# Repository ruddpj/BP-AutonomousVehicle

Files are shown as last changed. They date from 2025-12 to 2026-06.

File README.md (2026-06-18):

# Autonómne riadenie malého vozidla s detekciou prekážky
Autor: Rudolf Tisoň

plot

## 📌 Popis projektu
Tento projekt sa zameriava na autonómne riadenie malého vozidla pomocou počítačového videnia. Vozidlo dokáže sledovať jazdný pruh (čiaru) a zároveň detegovať prekážky v reálnom čase.

Na spracovanie obrazu sa využíva knižnica OpenCV a model YOLO, pričom riadenie vozidla zabezpečuje mikrokontrolér Arduino Nano ESP32 v kombinácii s kamerovým modulom ESP32-CAM.

## ⚙️ Použité technológie
🐍 Python

👁️ OpenCV

🤖 YOLO (You Only Look Once)

🔌 Arduino Nano ESP32

📷 ESP32-CAM

## 🚀 Funkcionalita
Detekcia jazdného pruhu (line following)

Detekcia prekážok pomocou YOLO

Rozhodovanie:

pokračovanie v jazde

zastavenie pri prekážke

Spracovanie obrazu v reálnom čase

Komunikácia medzi PC a mikrokontrolérom

## 🧠 Princíp fungovania
ESP32-CAM streamuje obraz do počítača

Python skript spracováva obraz:

OpenCV → detekcia jazdného pruhu

YOLO → detekcia prekážok

Na základe detekcie sa vypočíta:

- smer (steering)

- stav (jazda / stop)

Príkazy sa odošlú do Arduino Nano ESP32

Vozidlo reaguje na riadiace signály

## 🛠️ Inštalácia
1. Klonovanie repozitára
```bash
git clone https://github.com/ruddpj/BP-AutonomousVehicle.git
cd BP-AutonomousVehicle
```
2. Inštalácia závislostí
```bash
pip install opencv-python ultralytics numpy
```

## ▶️ Spustenie
```bash
python Python/main.py
```

## 🔌 Hardvér
- Arduino Nano ESP32

- ESP32-CAM + OV2640

- DRV8833

- HC-SR04

- 2x 3V 300RPM DC motory

- Buck menič nepätia

- Napájanie (batéria)

## 📂 Štruktúra projektu
```
.
├── Arduino/
├── Model/
├── Presentation/
├── Python/
├── Testing/
├── Thesis/
├── .gitignore
├── LICENSE
├── README.md
└── yolov8s.pt
```

## 🎓 Účel projektu
Projekt bol vytvorený ako súčasť štúdia (bakalárska práca) a slúži na demonštráciu využitia počítačového videnia v autonómnych systémoch.

## 📜 Licencia
Tento projekt je licencovaný pod GNU GPL-3.0

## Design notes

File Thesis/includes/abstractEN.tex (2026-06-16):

The objective of this bachelor's thesis was to design and implement a small vehicle capable of autonomous driving and obstacle detection using computer vision methods. The vehicle was equipped with an ESP32-CAM camera module and an ultrasonic sensor, which continuously monitored the area ahead and provided data for a control server operating in the Python programming language. An important element of the solution was image processing in the OpenCV library, where maintaining the vehicle within the center line of the lane was ensured through color thresholding and contour detection in a defined region of interest. For obstacle detection, a YOLOv8 convolutional neural network was integrated into the system, which, together with distance measurement, enabled the vehicle to respond smoothly to objects. The entire hardware system was controlled by the Arduino platform, while image processing took place on the server, which communicated wirelessly with the vehicle via Wi-Fi.

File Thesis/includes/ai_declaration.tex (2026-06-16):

\begin{trivlist}
\item Google (2026), Gemini 3 Fast, celý text, úprava štylizácie a reformulácia textu.

\item Google (2026), Gemini 3.1 Flash, abstrakt, preklad textu do angličtiny. 

\item OpenAI (2026), GPT-5.4, zdrojový kód, generovanie základnej štruktúry kódu pre Arduino, ESP32-CAM a server v jazykoch C++ a Python.
\end{trivlist}

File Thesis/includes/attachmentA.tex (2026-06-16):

\pagenumbering{Roman}
V prílohe sa nachádza archív \verb|zdrojovy_kod.zip| so zdrojovými kódmi pre vozidlo a server.
Zdrojový kód projektu je dostupný aj na:\par
\url{https://github.com/ruddpj/BP-AutonomousVehicle.git}.
\vspace*{50px}
\newline
\textbf{Arduino programy}
\begin{itemize}
	\item Arduino/
		\begin{itemize}
			\item ArduinoController/ArduinoController.ino
			\item WifiCamera/WifiCamera.ino
		\end{itemize}
\end{itemize}
\textbf{Python programy}
\begin{itemize}
	\item Python/
		\begin{itemize}
			\item connect.py
			\item detect.py
			\item interpret.py
			\item main.py
			\item remote.py
			\item transform.py
		\end{itemize}
\end{itemize}

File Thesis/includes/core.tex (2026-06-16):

\section{Autonómne vozidlá}\label{sec:AutonomneVozidla}
\subsection{Čo je to autonómne vozidlo?}\par
\acrfull{av}, niekedy nazývané aj samoriadiace auto je dopravný prostriedok, ktorý, na rozdiel od tradičných vozidiel nevyžaduje vodiča. Autonómne vozidlá vykonávajú túto úlohu pomocou viacerých hardvérových a softvérových systémov. Hoci ani v roku 2026 nemá termín 'samoriadiace' jednotnú štadardnú definíciu, hlavným cieľom týchto technológií zostáva eliminácia ľudských chýb, zvýšenie efektivity premávky a sprístupnenie prepravy ľudom, ktorí nie sú schopní šoférovať sami~\cite{wevolver2020}.\par
Na vnímanie okolia vozidla používame senzory detekcie objektov. Systém vnímania používa kamery, \acrfull{radar}, \acrfull{lidar} a ultrazvukové senzory, pričom každý z nich má špecifickú funkciu. Autonómne vozidlá často pracujú s čiastočne neznámym a dynamickým prostredím, preto si musia vystavať model svojho prostredia a zároveň sa v ňom lokalizovať. Tento proces je známy pod skratkou SLAM (súčasná lokalizácia a mapovanie)~\cite{wevolver2020}.\par
Spočíva v spracovaní dát zo senzorov, máp a systéme \glslink{gps}{globálneho polohovacieho systému} (\acrshort{gps}), vďaka čomu si zariadenie vytvorí model prostredia a určí v ňom svoju polohu v reálnom čase~\cite{wevolver2020}.\par
Tretí systém je zodpovedný za plánovanie a rozhodovanie. Na základe dát z predchádzajúcej vrstvy vozidlo vyhodnocuje a reaguje na vývoj dopravnej situácii. Táto vrstva má mnoho funkcií od plánovania trasy po vyhýbanie sa prekážkam. Najčastejšie sa používajú modely strojového učenia, vrátane neurónových sietí~\cite{wevolver2020}.\par
Posledným článkom je konanie a ovládanie. Systém ovládania vozidla premení abstraktné požiadavky predchádzajúcej vrstvy na fyzické pohyby auta. Zodpovedá za smerové riadenie, zrýchľovanie a brzdenie.\par
Pokročilé algoritmy zároveň zabezpečujú, aby pohyb bol plynulý, stabilný a rešpektoval limitácie podvozku. Vďaka integrácii týchto systémov dokáže autonómne vozidlo navigovať v komplexných dopravných situáciách s minimálnou až nulovou potrebou ľudského zásahu~\cite{wevolver2020}.
\subsection{Úrovne autonómnych vozidiel}
Úrovne autonómnych vozidiel sú definované organizáciou SAE International v štandarde SAEJ3016. Tento dokument delí automatizáciu riadenia do šiestich stupňov (0--5) podľa toho, akú časť jazdy zabezpečuje systém a akú úlohu ešte stále zohráva vodič. O samoriadiacich autách sa často hovorí, ako o jednej kategórii, no v praxi ide o postupný vývoj od minimálnej podpory riadenia až po úplnú autonómiu vozidla bez zásahu človeka~\cite{saej3016}.
\subsubsection{Úroveň 0}
\paragraph{Žiadna automatizácia}Na tejto úrovni všetky činnosti vykonáva ľudský vodič. Vozidlo môže mať bezpečnostné systémy, ako napríklad upozornenie opustenia jazdného pruhu, no samotné riadenie je plne v rukách človeka~\cite{saej3016}.
\subsubsection{Úroveň 1}
\paragraph{Asistované riadenie}Systém pomáha s postranným alebo pozdĺžnym riadením vozidla ale nie v obidvoch prípadoch naraz. Sem patria asistencie, ako udržiavanie rýchlosti (tempomat) alebo mierne korigovanie smeru. Vodič však musí neustále sledovať situáciu na vozovke a mať ruky na volante~\cite{saej3016}.
\subsubsection{Úroveň 2}
\paragraph{Čiastočná automatizácia}Vozidlo dokáže súčasne riadiť smer aj rýchlosť, stále však platí, že vodič nepretržite dohliada na jazdu a je pripravený zasiahnuť v prípade núdze. Systém vykonáva viac úloh riadenia naraz, no zodpovednosť upadá na človeka~\cite{saej3016}.
\subsubsection{Úroveň 3}
\paragraph{Podmienená automatizácia}Jazda v špecifickej situácii je automatizovaná a vodič nemusí aktívne sledovať okolie. Ak však systém vyhodnotí, že situáciu nezvládne, kontrola vozidla sa vráti vodičovi. Vodič musí byť pripravený prevziať kontrolu nad vozidlom~\cite{saej3016}.
\subsubsection{Úroveň 4}
\paragraph{Vysoká automatizácia}Na tejto úrovni je vozidlo schopné zvládnuť jazdu úplne samo v rámci definovaných prostredí alebo podmienok. V prípade, že sa vozidlo dostane mimo týchto podmienok, dokáže bezpečne zastaviť. Prítomnosť ľudského šoféra nie je nutná~\cite{saej3016}.
\subsubsection{Úroveň 5}
\paragraph{Plná automatizácia}Najvyšší stupeň automatizácie, vozidlo dokáže jazdiť samostatne za všetkých podmienok, v ktorých dokáže jazdiť človek. Neexistuje potreba vodiča. Vozidlo zastaví v prípade zlyhania určitých modulov riadenia~\cite{saej3016}.

\section{Ciele práce}\label{sec:CielePrace}
V tejto kapitole si stanovíme hlavný cieľ bakalárskej práce a taktiež čiastkové ciele, ktoré slúžia, ako miľníky pri praktickom spracovaní témy práce.\par
Hlavný cieľ bakalárskej práce je návrh a implementácia algoritmu pre autonómne riadenie malého robotického vozidla, ktoré dokáže v reálnom čase detegovať prekážky v jazdnej dráhe a následne na ne reagovať.\par
Praktická časť práce sa zameriava na implementáciu riešenia na hardvérovej platforme Arduino so súčasnými metódami počítačového videnia pomocou knižnice OpenCV.\par
\subsection{Čiastkové ciele}
\begin{enumerate}
	\item \textbf{Analýza problematiky:} Teoretické spracovanie aktuálnej problematiky v oblasti autonómnych vozidiel. Zhodnotenie súčasnej a budúcej implementácie jednotlivých systémov použitých v \acrshort{av}. Prehľad konkrétneho využitia senzorových systémov a umelej inteligencie na detekciu prekážok.

	\item \textbf{Návrh technologického riešenia:} Výber optimálnej kombinácie hardvérových a softvérových komponentov v rámci obmedzenia bakalárskej práce. Zvolenie riadiacej jednotky Arduino, typ a počet senzorov, programovací jazyk riešenia a mechanické prvky vozidla. Výber metód detekcie prekážky a jazdného pruhu pomocou počítačového videnia. Fyzický návrh vzhľadu vozidla so zameraním na použité materiály a rozloženie komponentov.

	\item \textbf{Algoritmizácia detekcie:} Zvolenie riešení v prostredí OpenCV zameraných na spracovanie obrazu z kamery na identifikáciu prekážok a jazdného pruhu v zornom poli vozidla.

	\item \textbf{Prepojenie komponentov:} Návrh metód komunikácie jednotlivých komponentov. Prepojenie vrstiev riadenia autonómneho vozidla od vnímania po konanie. Interpretácia výstupov na vstupy pre jednotlivé systémy. Návrh fyzického prepojenie častí systému pomocou komunikačného média.

	\item \textbf{Zostavenie riešenia:} Implementácia zvolených návrhov. Naprogramovanie riešenia s použitím knižnice OpenCV. Zostavenie rámu vozidla a následná montáž.

	\item \textbf{Testovanie a validácia:} Navrhnutie metodiky testovania a následné overenie funkčnosti vozidla v rozličných situáciách. Otestovanie detekcie rôznych prekážok.
\end{enumerate}

\section{Analýza súčasného stavu}\label{sec:Analyza}
\subsection{Aktuálny stav technológie}
V posledných rokoch sme zaznamenali nárast vozidiel s treťou úrovňou autonómie, autonómne taxi služby sa v mestách stávajú reálnym spôsobom dopravy a videli sme už aj prvé ukážky kamiónov bez nutnosti ľudského vodiča~\cite{electronics2022}\cite{mckinsey2026}.\par
Vďaka vývoju v oblasti umelej inteligencie a zvýšenia výkonu výpočtových platforiem sme zaregistrovali značný pokrok v technológiách autonómnych vozidiel. Výrobcovia sa snažia zlepšovať kombinácie \glslink{radar}{radarových}, \acrshort{lidar}ových a kamerových dát tak, aby boli robustnejšie voči dopravným a poveternostným podmienkam. Pokračuje snaha v návrhu scenárov pre hraničné situácie, čím sa zlepší percepčná schopnosť autonómnych systémov a zrýchli ich nasadenie~\cite{motortrend2026}\cite{nvidia2026}.\par
Autonómne vozidla zaznamenali značnú investíciu ale aj kontrolu zo strany štátnych a nadnárodných organizácií. Spoločnosti, ktoré poskytujú služby samoriadiacich vozidiel rozširujú svoju dostupnosť, znižujú počet senzorov a náklady na hardvér. Hoci technologický pokrok napreduje, integrácia do infraštruktúry mesta zostáva podstatnou výzvou pre adopciu \acrshort{av} do dopravy. Štandard SAE International preto opisuje plán prechodu od asistencie šoférovania po plne autonómnu prevádzku~\cite{theguardian2026}\cite{waymo2026}.
\subsubsection{Umelá inteligencia}
\acrfull{ai} vykonáva dôležitú funkciu v percepčnom, rozhodovacom a plánovacom systéme autonómneho vozidla, čím nahrádza rolu ľudského vodiča. Moderné systémy používajú strojové učenie (machine learning) na detekciu hazardov na ceste, klasifikáciu dopravných značiek a sledovanie a predikciu pohybu chodcov a ostatných vozidiel~\cite{hamza2023}.\par
V súčasnosti sa autonómne modely trénujú na obrovskom množstve anotovaných obrázkov, videí, simulácií a skutočných jazdných dát, aby v praxi zvládli širokú škálu scenárov. Hlboké učenie (deep learning) a učenie posilňovaním (reinforcement learning) sa používajú v novodobých autonómnych vozidlách. Deep learning, podskupina strojového učenia, pracuje na princípe viacvrstvových neurónových sietí, čím sa fungovaním podobá ľudskému mozgu. Reinforcement learning mení správanie modelu využitím systému odmien a penalizácií~\cite{grigorescu2019}.\par
Napriek značnej komplexnosti zostáva riešenie hraničných prípadov (edge cases) zásadnou výzvou pre dnešné systémy. Potreba veľkého množstva tréningových dát a vysoká hranica bezpečnosti a spoľahlivosti výrazne spomaľuje nasadenie vozidiel do reálnej premávky~\cite{nvidia2026}.
\subsubsection{Senzory}
Senzory sú spôsob akým autonómne vozidlá vnímajú svoje okolie. Ako je možné vidieť na obrázku \ref{fig:sensors}, v súčasnosti sa v autách využíva kombinácia kamier, \acrshort{lidar}ových, \glslink{radar}{radarových} a ultrazvukových senzorov~\cite{badue2021}.\par
\begin{figure}[!ht]
	\centering
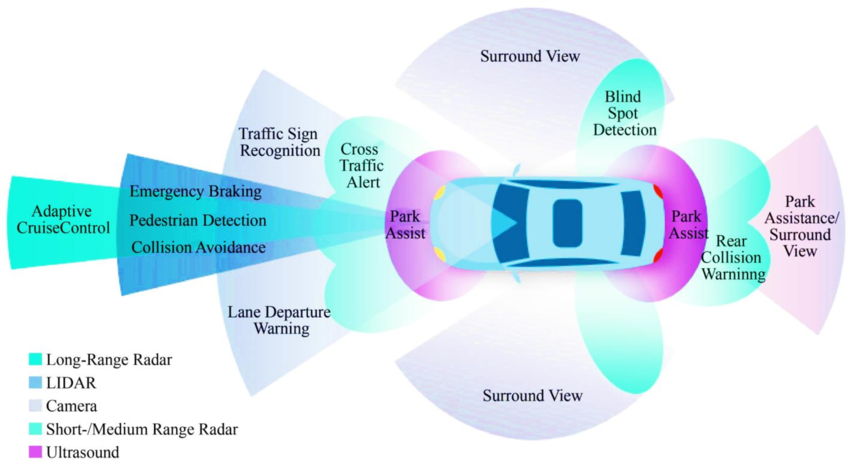
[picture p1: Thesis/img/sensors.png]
	
	\caption{Ako \acrshort{av} vnímaju prostredie}
	\parbox{9cm}{\centering\footnotesize{\cite{hamza2023}, licencia: \href{https://creativecommons.org/licenses/by-sa/4.0/deed.en}{CC BY-SA 4.0}.}}
	\label{fig:sensors}
\end{figure}
Kamery predstavujú najrozšírenejší typ senzorov; sú nákladovo efektívne, no citlivé na zlé osvetlenie a počasie. Používajú sa na detekciu jazdných pruhov, rozpoznávanie dopravných značiek a identifikáciu chodcov a vozidiel. \acrshort{radar} využíva elektromagnetické vlny na meranie vzdialenosti a rýchlosti. Používa sa najmä pre detekciu vzdialených objektov aj v nepriaznivých poveternostných podmienkach (dážď, hmla, sneh). \acrshort{lidar} používa laserové impulzy na vytvorenie detailného trojrozmerného modelu okolia, no okrem vysokých nákladov je aj viac náchylný na zlé počasie. Ultrazvukové senzory majú využitie v detekcii objektov na krátke vzdialenosti, napríklad pri parkovacích manévroch. Na rozdiel od fotoelektrických senzorov (napr. \acrshort{radar}), nie sú ovplyvnené farbou alebo odrazivosťou cieľa, pretože používajú zvuk a nie svetlo~\cite{wevolver2020}\cite{badue2021}.\par
Súčasný vývoj v oblasti senzorov sa zameriava primárne na zvyšovanie presnosti meranie, optimalizovanie počtu potrebných senzorov a výrazné znižovanie ich ceny. Výrobcovia taktiež zefektívňujú kombinovanie dát viacerých senzorov, tzv. senzorovú fúziu, čím zvyšujú presnosť a spoľahlivosť systému~\cite{waymo2026}\cite{hamza2023}.
\subsection{Použitie autonómnych vozidiel}
Autonómne vozidlá ponúkajú široké spektrum využitia, pričom ich možnosti sa v posledných rokoch rozširujú. K najpozoruhodnejším oblastiam ich využitia patrí doprava. Hlavným cieľom je zvýšiť bezpečnosť a plynulosť premávky. Ďalšie využitie je v logistike tovaru, kde nahrádzajú rutinnú manuálnu prácu tradične vykonávanú ľudmi.\par
\subsubsection{Autonómne taxi služby}
Autonómne taxi služby, často nazývané robotaxíky, predstavujú jednu z najpokročilejších foriem využitia autonómnych technológií. Celý proces -- od objednania a naplánovania trasy až po samotnú prepravu pasažierov -- je plne automatizovaný.\par
Mnohí výrobcovia automobilov, technologické spoločnosti a štátne organizácie investujú zdroje do vývoja robotaxíkov. Na popredí stojí spoločnosť Waymo, dcérska spoločnosť amerického konglomerátu Alphabet. Ich vozidlá, spĺňajúce štvrtú úroveň autonómie, využívajú \acrshort{lidar}, \acrshort{radar} a kamery na vytváranie trojrozmerného obrazu okolia. S každou ďalšou generáciou vozidiel navyše redukujú počet senzorov, čím znižujú výrobné náklady a zlepšujú škálovateľnosť celého projektu~\cite{waymo2026}.\par
Alternatívny prístup zvolila spoločnosť Tesla so svojou službou Robotaxi a systémom FSD (Full Self-Driving), ktorý predstavuje tretí stupeň autonómneho riadenia. Na rozdiel od konkurencie nepoužíva finančne nákladné \acrshort{lidar} senzory, ale spolieha sa výhradne na kamerový systém s interpretáciou dát pomocou umelej inteligencie. Hoci pri bežných vozidlách nad jazdou stále dohliada ľudský operátor pripravený kedykoľvek prevziať kontrolu, v roku 2026 začala spoločnosť do svojej flotily zavádzať prvé vozidlá v plne autonómnom režime bez ľudského dozoru~\cite{notateslaapp2026}.\par
Ďalším významným hráčom je spoločnosť Nvidia s modelom Alpamayo 1. Tento open-source model uvažovania je navrhnutý a trénovaný špeciálne na zvládanie komplexných a kritických dopravných situácií. Vydanie tohto voľne dostupného riešenia má za cieľ výrazne urýchliť integráciu štvrtej a piatej úrovne \acrshort{av} do bežnej premávky~\cite{nvidia2026}.
\subsubsection{Autonomizácia donášky jedla}
\glslink{adr}{Autonómne doručovacie roboty}~(\acrshort{adr}) sa používajú v súčasnosti v univerzitných kampusoch a mestách na donášku jedla. Poskytujú takzvanú last-mile delivery (dodanie na poslednú míľu) a fungujú na štvrtej úrovni autonómie. Primárne využívané na chodníkoch alebo cyklochodníkoch, doručovacie roboty sú schopné prekonávať križovatky, vyhýbať sa prekážkam a doručovať tovar na vzdialenosť pár kilometrov~\cite{srinivas2022}.\par
\acrshort{adr} používajú zväčša kombináciu kamier a počítačového videnia na navigovanie, týmto spôsobom zabezpečujú nižšie náklady na výrobu, s väčšou mierou škálovateľnosti. Niektorí výrobcovia sa vyhýbajú používaniu \acrshort{gps}, pretože neposkytuje dostatočnú mieru presnosti~\cite{forbes2025}.\par
Autonómna donáška jedla zaznamenala výrazný rozvoj počas pandémie COVID-19. Mnohé spoločnosti poskytujúce donášku jedla, ako napríklad Uber Eats a DoorDash, ale aj logistické spoločnosti, ako Amazon, Walmart a Google začali investovať do vývoja \acrshort{adr}. Jedným z priekopníkov v tejto oblasti je spoločnosť Starship Technologies, ktorá výrazne rozšírila svoju flotilu práve počas pandémie. Zatiaľ čo donáška pomocou pozemných robotov je bežná, mnohé spoločnosti investujú aj do vývoja doručovania pomocou autonómnych dronov~\cite{forbes2025}.\par
Značným problémom \acrshort{adr} je ich krátky dosah, pomalá rýchlosť a obmedzená kapacita užitočného zaťaženia. Mnohé spoločnosti investujú do hybridných modelov donášky kombináciou konvenčných donáškových vozidiel a doručovacích robotov~\cite{srinivas2022}.\par
V závislosti od charakteristík systému možno existujúci model hybridného doručovania klasifikovať, ako nasledujúce tri kategórie:
\begin{itemize}
	\item \textbf{Dvojúrovňový model:} Tento model využíva konvenčné vozidlá (kamióny alebo dodávky) na hromadnú prepravu zásielok z centrálneho depa do siete menších lokálnych skladísk. Z týchto miest vykonávajú \acrshort{adr} donášku na poslednú míľu priamo zákazníkovi~\cite{srinivas2022}.
	\item \textbf{Mothership model:} V tomto modeli slúži štandardné doručovacie vozidlo ako materská loď, ktorá je špeciálne upravená na prepravu flotily \acrshort{adr}. Autonómne roboty sa z materskej lode vypúšťajú v bezprostrednej blízkosti koncových adries doručenia. Ide o jeden z najčastejšie skúmaných modelov v aktuálnej literatúre~\cite{srinivas2022}.
	\item \textbf{Model čaty} Autonómne vozidlá doručujú zásielky samostatne v oblastiach, ktoré sú schopné navigovať. Ak však musia prekonať zóny, ktoré sú pre roboty nedostupné, pripoja sa k manuálne riadenému vozidlu, ktoré funguje ako ,,vodca čaty''. Roboty nasledujú toto vozidlo, až kým nedorazia do zóny im vhodnej~\cite{srinivas2022}.
\end{itemize}
\subsection{Zhrnutie poznatkov}
Po analýze technologického vývoja autonómnych vozidiel je nevyhnutné kriticky zhodnotiť ich dopad na reálne dopravné prostredie. V nasledujúcej podkapitole si identifikujeme aktuálne trendy a vyvodíme poznatky, ktoré formujú súčasnú sféru autonómnej mobility.\par
Mnohé implementácie v priemysle autonómnych vozidiel sa posúvajú od asistovaných systémov úrovne 2 a 3, k plne autonómnej prevádzke v špecifických podmienkach úrovne 4. Plná autonómia úrovne 5 stále ostáva dlhodobým problémom v danej oblasti.\par
Počet senzorov sa v autonómnych vozidlách zdatne zmenšuje. Prechádza sa z ideológie ,,maximálnej redundancie'' s vysokým počtom senzorov na optimalizovaný prístup. Spoločnosti, ako Tesla nahrádzajú spoľahlivé, no ekonomicky nevýhodné \acrshort{lidar}ové senzory za kombináciu kamier a \acrshort{ai}.\par
Kontrastne, spoločnosti ako Waymo sa držia prístupu založeného na \acrshort{lidar}e, no snažia sa znížiť cenu a zvýšiť ich efektivitu. V súčasnosti ešte neexituje konsenzus medzi technologickými spoločnosťami.\par
\acrshort{ai} zohráva dôležitú rolu pri plánovacom a rozhodovacom systéme autonómnych vozidiel. Súčasné trendy ukazujú na využívanie jazykových modelov, ktoré sú schopné interpretovať dáta zo senzorov a z nich priamo rozhodnúť o chode autonómneho vozidla.\par
Hraničné situácie zohrávajú najväčšiu bariéru ku masovému nasadeniu autonómnych vozidiel úrovne 5. Vývoj v oblasti umelej inteligencii sa zameriava práve na tieto edge cases. Z analýzy vyplýva, že vyriešením tohto problému, bude zavedenie \acrshort{av} v mestách zdatne urýchlené.\par
Technológia samotná nestačí pre adopciu autonómnych vozidiel do miest. Značným problémom je integrácia v mestskom prostredí a verejná akceptácia \acrshort{av}. Predpokladáme, že krajiny, ktoré budú investovať do integrácie autonómnych vozidiel, a ktoré majú progresívny názor na ich nasadenie, budú zaznamenávať najväčší nárast v tomto sektore.\par
Viaceré z identifikovaných aspektov boli priamo reflektované v našom návrhu systému autonómneho vozidla s detekciou prekážok.

\section{Komponenty systému}\label{sec:Komponenty}
V tejto kapitole si preberieme použité komponenty celkového systému. Výber správnych súčastí v rámci limitácií bakalárskej práce je dôležitý pre získanie lepších výsledkov.
\subsection{Arduino Nano ESP32 mikrokontrolér}
Arduino je talianska open-source hardvérová a softvérová spoločnosť, ktorá navrhuje a vyrába mikrokontroléry určené na vývoj rôznych zariadení. Rodina mikrokontrolérov Arduino Nano predstavuje radu kompaktných a cenovo dostupných dosiek. Konkrétne model Nano ESP32 je osadený čipom ESP32-S3, ktorý integruje možnosti Wi-Fi a Bluetooth bezdrôtového pripojenia. Tento mikrokontrolér poskytuje optimálny pomer veľkosti a výkonu, s dostatočným počtom pinov na pripojenie periférií~\cite{arduino}.\par
V tejto práci sa Arduino Nano ESP32 používa ako riadiaca jednotku, ktorá získava vstupy od ostatných komponentov a podľa nich riadi mechanické časti vozidla~\cite{arduino}.\par
\begin{figure}[!ht]
	\centering
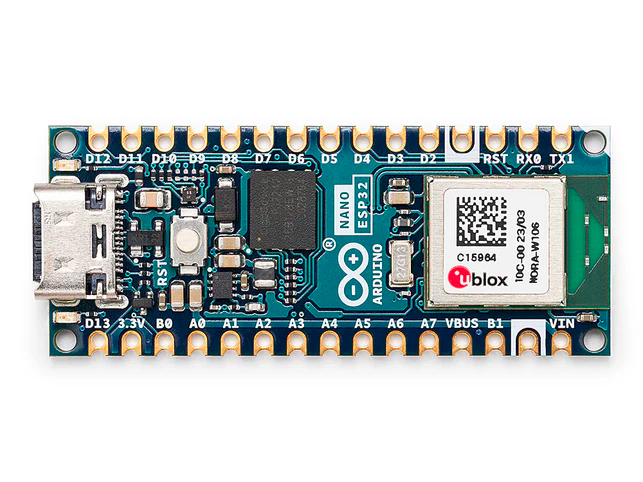
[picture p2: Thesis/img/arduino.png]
	
	\caption{Arduino Nano ESP32}
	\parbox{9cm}{\centering\footnotesize{autor: Arduino, zdroj: arduino.cc, licencia: \href{https://creativecommons.org/licenses/by-sa/4.0/deed.en}{CC BY-SA 4.0}.}}
	\label{fig:arduino}
\end{figure}
\clearpage
\noindent\textbf{Technické parametre:}
\begin{itemize}
	\item Rozmery: 18 * 45 mm
	\item Vstupné/výstupné napätie: 3,3 V
	\item Počet \acrshort{gpio} pinov: 48
	\item Komunikačné rozhrania: UART, I2C, SPI
	\item Rýchlosť procesora: 240 Mhz
	\item Veľkosť ROM: 384 kB
	\item Veľkosť S\acrshort{ram}: 512 kB
	\item Veľkosť \acrshort{ram}: 8 MB
\end{itemize}
\subsection{ESP32-CAM + OV2640 kamera}
Vývojová doska ESP32-CAM integruje Wi-Fi a Bluetooth modul spolu s rozhraním na pripojenie 2 Mpx kamerového senzora OV2640. Táto kombinácia poskytuje oddelenú implementáciu prenosu videa, čím sa odľahčí výpočtová záťaž hlavného čipu. Senzor OV2640 disponuje natívnym rozlíšením 1600 x 1200 pixelov a snímkovou frekvenciou 60 FPS, čo poskytuje dostatočnú výkonovú rezervu~\cite{esp32cam}\cite{ov2640}.\par
\begin{figure}[!ht]
	\centering
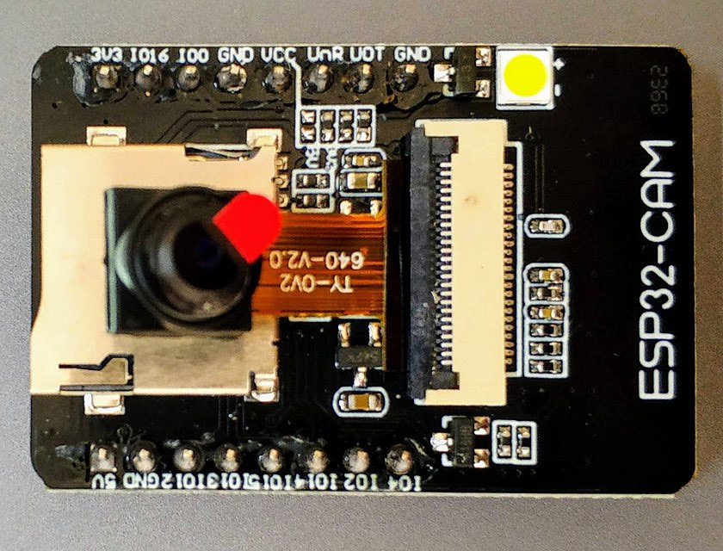
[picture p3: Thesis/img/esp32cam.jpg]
	
	\caption{ESP32-CAM a OV2640}
	\parbox{9cm}{\centering\footnotesize{ESP32-CAM, autor: Nowforever, zdroj: Wikimedia Commons, licencia: \href{https://creativecommons.org/licenses/by-sa/4.0/deed.en}{CC BY-SA 4.0}.}}
	\label{fig:esp32cam}
\end{figure}
\clearpage
\noindent\textbf{Technické parametre:}
\begin{itemize}
	\item Rozmery: 27 * 40 mm
	\item Pracovné napätie: 2,2 - 3,6 V
	\item Rozlíšenie kamery: 1 600 x 1 200
	\item Frame rate kamery: 60 FPS (pri CIF formáte)
	\item Rýchlosť procesora: 240 Mhz
	\item Veľkosť FLASH: 4 MB
	\item Veľkosť PS\acrshort{ram}: 4 MB
\end{itemize}
\subsection{HC-SR04 Ultrazvukový senzor}
Ultrazvukový senzor HC-SR04 predstavuje nákladovo efektívne riešenie na detekciu objektov pred vozidlom. Tento senzor slúži ako sekundárny systém pre núdzové zastavenie v prípadoch, kedy primárny kamerový systém zlyhá pri detekcii prekážky~\cite{hcsr04}.\par
\begin{figure}[!ht]
	\centering
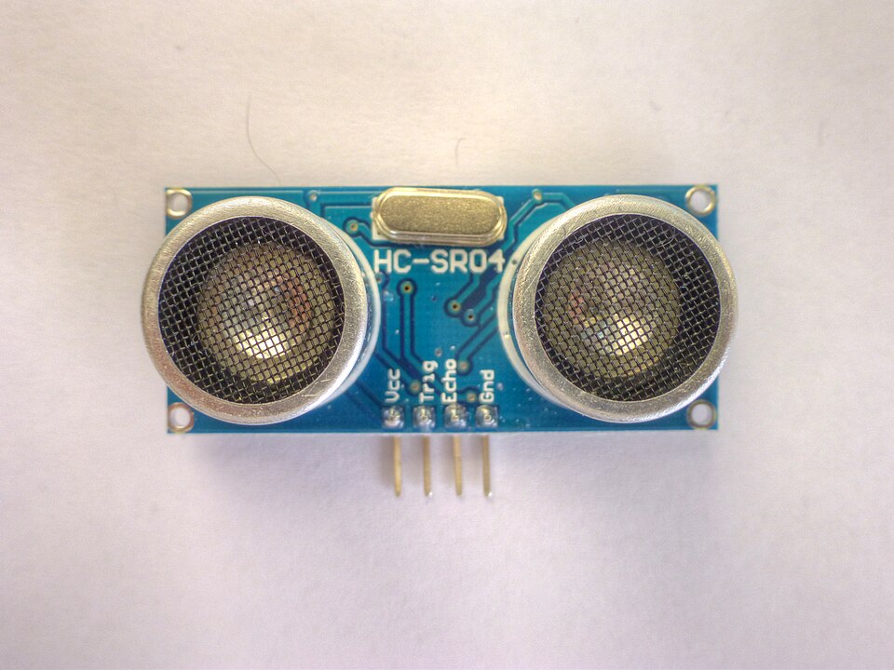
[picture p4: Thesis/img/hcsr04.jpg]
	
	\caption{HC-SR04 ultrazvukový modul}
	\parbox{9cm}{\centering\footnotesize{HC SR04 Ultrasonic Module, autor: Nevit Dilmen, zdroj: Wikimedia Commons, licencia: \href{https://creativecommons.org/licenses/by-sa/3.0/deed.en}{CC BY-SA 3.0}.}}
	\label{fig:hcsr04}
\end{figure}
\clearpage
\noindent\textbf{Technické parametre:}
\begin{itemize}
	\item Rozmery: 20 * 45 * 15 mm
	\item Pracovné napätie: 5 V
	\item Maximálna vzdialenosť: 4 m
	\item Minimálna vzdialenosť: 2 cm
	\item Merací úhol: 15°
\end{itemize}
\subsection{DRV8833 driver pre motorčeky}
Modul DRV8833 bol použitý na nezávislé riadenie dvoch \acrshort{dc} motorov. Integrovaný obvod obsahuje dvojitý H-mostík, ktorý umožňuje meniť polaritu napätia, a tým aj smer otáčania motorov. Modul má štyri vstupné piny (dva pre každý motor), pomocou ktorých možno ovládať rýchlosť a smer otáčania~\cite{drv8833}.\par
\begin{figure}[!ht]
	\centering
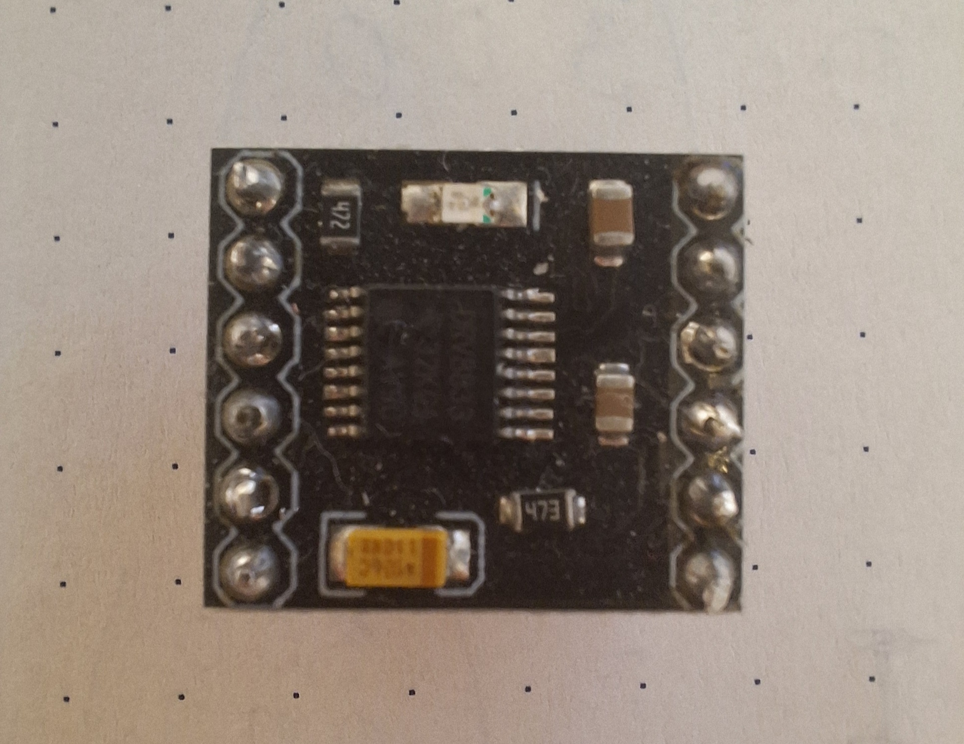
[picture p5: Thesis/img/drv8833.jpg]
	
	\caption{DRV8833 driver pre motorčeky}
	\label{fig:drv8833}
\end{figure}
\noindent\textbf{Technické parametre:}
\begin{itemize}
	\item Rozmery: 5 * 4 mm
	\item Logické napätie: 2,7 - 10,8 V
	\item Drive napätie: 3 - 10 V
	\item Drive prúd: 1,5 A (MAX pre jeden mostík)
	\item Maximálny výkon: 15 W
\end{itemize}
\subsection{Ďalšie elektrické komponenty}
V implementácii je použité 18650 Li-Ion akumulátor s napätím 7,4 V a kapacitou 3 000 mAh.\par
Pohon zabezpečujú dva GA12-N20 \acrshort{dc} motory s prevodovkou s rýchlosťou 200 \acrshort{rpm} pri napätí 3 V.\par
Z dôvodu ochrany komponentov je do systému zapojený znižujúci menič napätia (step-down buck converter). Použitý menič disponuje dvojvodičovým vstupom a výstupom v podobe dvoch konektorov USB-A. Zabudovaný LM2596 čip reguluje široké pásmo napätí na 5 V s výstupným prúdom 3 A.\par
Súčasťou zapojenia je taktiež trojpólový, dvojpolohový MTS-102 prepínač na zapnutie a vypnutie celého systému.\par
Prepojenie jednotlivých komponentov zabezpečuje nepájivé pole a spojovacie vodiče.
\subsection{Server}
Vzhľadom na obmedzený výpočtový výkon mikrokontrolérov Arduino, ktoré nie sú schopné vykonávať komplexné výpočty neurónových sietí v reálnom čase, sme do systému zaradili centrálny server. Ten zabezpečuje spracovanie obrazu a koordináciu bezdrôtových periférií. V našej implementácii túto úlohu plní laptop, ktorý zároveň slúži ako prístupový bod pre Wi-Fi sieť.

\section{Softvér}\label{sec:Softver}
V nasledovnej časti sa oboznámime s použitým softvérom, ktorý nám umožňuje preklad požiadaviek systému na skutočné inštrukcie vykonateľné hardvérom.
\subsection{C++}
C++ je programovací jazyk vyššej úrovne na všeobecné použitie, ktorý zároveň umožňuje prácu s prostriedkami nízkej úrovne. Bjarne Stroustrup vyvinul C++ v roku 1983 ako rozšírenie jazyka C~\cite{stroustrupcpp}.\par
Mikrokontroléry Arduino sa programujú v jazykoch C/C++ pomocou štandardného \glslink{api}{rozhrania pre programovanie aplikácií} (\acrshort{api}), ktoré je známe ako Arduino Programming Language. Toto \acrshort{api} poskytuje funkcie a knižnice určené na ovládanie hardvéru. Súčasťou projektu Arduino je aj vývojové prostredie Arduino \acrshort{ide}, ktoré zjednodušuje kompiláciu, integráciu knižníc a samotné nahrávanie kódu~\cite{arduino}.\par
V našej implementácii používame C++ pre programovanie nízkoúrovňového mikrokontroléru Arduino Nano ESP32 a kamerového modulu ESP32-CAM.
\subsection{Python}
Python je interpretovaný, interaktívny programovací jazyk vysokej úrovne, ktorý vytvoril Guido van Rossum. Je dynamicky typovaný, čo znamená, že typ premennej sa určuje za behu programu. Na rozdiel od jazykov C/C++, využíva Garbage Collection, vďaka čomu programátor nemusí manuálne riešiť alokovanie a uvoľňovanie pamäte. Štruktúra kódu je definovaná odsadením, čím sa výrazne zvyšuje čitateľnosť kódu~\cite{kuhlmanpython}.\par
V našej implementácii používame Python na vytvorenie Wi-Fi servera, spracovanie dát z kamery a následnú interpretáciu výsledkov do podoby príkazov pre pohyb kolies.
\subsection{OpenCV}
OpenCV je knižnica programovacích funkcií určených na počítačové videnie v reálnom čase, ktorú pôvodne vyvinula spoločnosť Intel. Využíva sa v oblastiach detekcie objektov, tvárí a gest, pri vizuálnej odometrii, vnímaní hĺbky či v augmentovanej realite. Knižnica OpenCV je napísaná v programovacom jazyku C++, no ponúka rozhrania pre integráciu v ďalších jazykoch, ako sú Python, Java alebo MATLAB~\cite{acm2012}\cite{opencv2025}.\par
V našej implementácii používame OpenCV na detekciu vozovky a analýzu jazdných pruhov.
\subsection{NumPy}
NumPy je knižnica pre programovací jazyk Python, ktorá pridáva podporu pre optimalizované polia, matice a matematické funkcie, ktoré s nimi pracujú~\cite{numpy}.\par
Python interpretuje inštrukcie riadok po riadku, čo spomaľuje celkový program. Knižnica NumPy urýchľuje tento proces tým, že vykonáva výpočtovo náročné operácie vo vysoko optimalizovanom, kompilovanom C kóde. Taktiež mnoho operácií uvoľňujú globálny zámok interpreteru, čím dovoľuje paralelné spúšťanie viacerých vlákien viacjadrového procesora. Horeuvedená knižnica OpenCV používa NumPy na ukladanie dát a operácie s nimi~\cite{opencv2025}\cite{numpy}.\par
V našej implementácii používame knižnicu NumPy na prácu s vektormi a maticami pri transformácii obrazových dát.
\subsection{CNN}
\acrfull{cnn}, po slovensky konvolučná neurónová sieť, je typ doprednej neurónovej siete, ktorá používa optimalizáciu filtrov. Tento typ hlbokej neurónovej siete sa štandardne používa pri počítačovom videní a spracovaní obrazu~\cite{cnnvc}.\par
Konvolučné neurónové siete sa skladajú z rôznych vrstiev. Hlavným stavebným prvkom je takzvaná konvolučná vrstva, ktorá obsahuje rôzne filtre -- matice váh. Počas doprednej propagácie sa po celej výške a šírke vstupnej matice počíta skalárny súčin pre každý filter konvolučnej vrstvy. Výsledkom je dvojrozmerná aktivačná mapa daného filtra. \acrshort{cnn} sa učia vytvárať filtre, ktoré sa aktivujú v prípade, že sa na vstupe nachádza požadovaná vlastnosť~\cite{cnnvc}.\par
Ďalšie vrstvy, ako združovacia (pooling) vrstva sa používa na zmenšenie rozmerov vstupnej matice, ReLU vrstva na odstránenie záporných hodnôt a plne prepojená (fully connected) vrstva na finálnu klasifikáciu. Obrázok \ref{fig:cnn} zobrazuje bežnú konvolučnú neurónovú sieť~\cite{cnnvc}.\clearpage
\begin{figure}[!ht]
	\centering
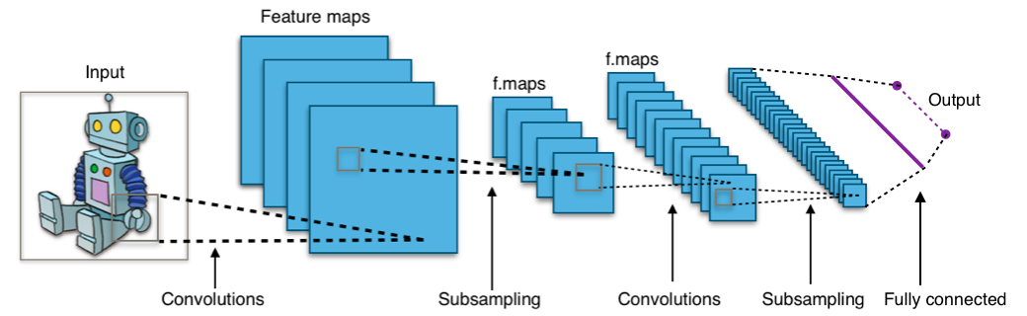
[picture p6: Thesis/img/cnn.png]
	
	\caption{Typická CNN}
	\parbox{9cm}{\centering\footnotesize{Fully connected convolutional neural network, autor: Aphex34, zdroj: Wikimedia Commons, licencia: \href{https://creativecommons.org/licenses/by-sa/4.0/deed.en}{CC BY-SA 4.0}.}}
	\label{fig:cnn}
\end{figure}
\acrshort{cnn} dosahujú pri analýze obrazového vstupu výrazne nižšiu chybovosť a efektívnejší proces učenia v porovnaní s inými typmi neurónových sietí. V súčasnosti sa konvolučné neurónové siete používajú na detekciu prekážok v autonómnych vozidlách, no objavuje sa rastúci trend prechodu na veľké jazykové modely (LLM), ktoré ovládajú všetky systémy vozidla~\cite{electronics2022}\cite{nvidia2026}\cite{ciregan2012}.\par
\subsubsection{Ultralytics YOLOv8}\label{subsubsec:yolo}
\acrshort{yolo}v8 je systém od spoločnosti Ultralytics určený na detekciu objektov v reálnom čase; funguje na základe konvolučných neurónových sietí. Metóda \acrfull{yolo} vyžaduje iba jednu doprednú propagáciu (forward pass) na vytvorenie predpokladu, preto je ideálna pre aplikácie v reálnom čase~\cite{make2023}\cite{yolo2023}.\par
\acrshort{yolo}v8 ponúka päť veľkostí modelov: nano, small, medium, large a extra-large, ktoré predstavujú kompromis medzi rýchlosťou a presnosťou. Tieto modely sú predtrénované na rozsiahlych datasetoch, vďaka čomu sú pripravené na okamžité nasadenie bez potreby zložitej konfigurácie~\cite{yolo2023}.\par
V našej implementácii využívame veľkosť modelu \textit{small} na detekciu prekážky v dráhe vozidla.

\section{Návrh a implementácia}\label{sec:NavrhAImplementacia}
Správny návrh architektúry je dôležitý pre efektívne fungovanie všetkých komponentov. Počas vývoja bolo otestovaných niekoľko prístupov, kým sa nepodarilo dosiahnuť optimálne riešenie. V tejto kapitole popíšeme použitý dizajn a jeho následnú implementáciu.
\subsection{Detekcia vozovky}
Detekcia jazdných pruhov a hraníc vozovky predstavuje jeden z kritických subsystémov autonómnych vozidiel. Jej hlavnou úlohou je identifikovať cestu, udržať vozidlo v jazdnom pruhu a správne zareagovať v prípade zmien vozovky. \acrshort{av} sú schopné túto funkciu vykonávať pomocou fúzie rôznych senzorov~\cite{badue2021}.\par
Táto podkapitola sa zaoberá metódami spracovania dát, ktoré umožňujú systému rozoznať vozovku od prostredia. Na tento účel používame metódy a funkcie dostupné v programovacom jazyku Python, ako aj v knižniciach NumPy a OpenCV. Tieto knižnice boli do vývojového prostredia nainštalované pomocou správcu balíkov pip.
\subsubsection{Region of interest}
V kontexte autonómnych vozidiel sa \acrshort{roi} používa na ohraničenie určitej oblasti obrazového vstupu kamier, ktorá je pre daný systém detekcie relevantná~\cite{opencv2025}.\par
Pri implementácii detekcie vozovky bol použitý \acrshort{roi} ako prvý krok predspracovania. Vozovka sa vo väčšine prípadov nachádza v spodnej polovici obrazu, pričom spracovanie hornej časti zbytočne vnáša nepotrebné informácie. To spôsobuje vizuálny šum a zaťaženie procesora.\par
Na extrakciu \acrshort{roi} boli použité funkcie dostupné v knižnici OpenCV.\par
\begin{lstlisting}[language=Python, caption=Funkcia ROI]
def region_of_interest(frame):
    h, w = frame.shape[:2]
    roi_height = 100
    roi_mask = np.ones_like(frame) * 255

    roi_mask[h - roi_height:h, :] = frame[h - roi_height:h, :]

    return roi_mask
\end{lstlisting}
Proces začal vytvorením pomocnej matice s rovnakými rozmermi ako vstupný obraz, pričom všetky jej prvky boli nastavené na maximálnu hodnotu 8-bitového rozsahu (255). Táto matica bola definovaná pomocou knižnice NumPy. Následne do nej bola skopírovaná relevantná časť obrazu od vopred definovanej vertikálnej hranice \verb|roi_height| smerom nadol. Výsledok, viditeľný na obrázku \ref{fig:roi}, predstavuje obraz, kde sú spracované len tie pixely, ktoré sú v spodnej polovici obrazu a pravdepodobne obsahujú informácie o vozovke.\par
\begin{figure}[!ht]
	\centering
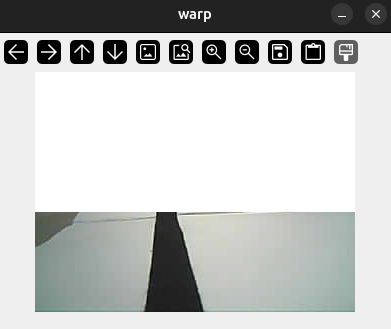
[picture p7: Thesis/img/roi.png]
	
	\caption{Obraz s použitím ROI}
	\label{fig:roi}
\end{figure}
\subsubsection{Hľadanie tmavých regiónov}
Hľadanie tmavých regiónov na vozovke je jednoduchý a výpočtovo nenáročný spôsob detekcie jazdných pruhov. Autonómne vozidlá dokážu detegovať svetlý jazdný pruh na tmavom asfalte vďaka kontrastu týchto dvoch plôch. V princípe je použitý rovnaký prístup, no v tejto implementácii sa hľadá čierny pruh v strede bielej vozovky~\cite{opencv2025}.\par
Prvým krokom je definícia hraníc pre najsvetlejší a najtmavší tmavý región. V kóde sú tieto hranice definované ako NumPy pole s reprezentáciou vo formáte odtieň-sýtosť-jas (HSV). Odtieň (hue) predstavuje hodnotu od 0 po 179 -- čiže polohu na farebnom kolese. Sýtosť (saturation) je percentuálne vyjadrenie ,,čistoty'' farby, teda množstva sivej farby, kde sa volia hodnoty od 0 po 255. Jas (value) určuje intenzitu svetla, kde hodnota 0 predstavuje absolútnu čiernu, zatiaľ čo hodnota 255 zodpovedá maximálnemu jasu farby~\cite{opencv2025}.\par
\begin{lstlisting}[language=Python, caption=Definície maxima a minima tmavých regiónov]
lower_black = np.array([0, 0, 0])
upper_black = np.array([180, 255, 70])
\end{lstlisting}
V ďalšom kroku sa konvertuje obraz z kamery z pôvodného formátu BGR (blue-green-red) na HSV reprezentáciu pomocou OpenCV funkcie \verb|cvtColor| s argumentom \verb|COLOR_BGR2HSV|. Volaním funkcie \verb|inRange| s vopred definovanými hranicami sa vygeneruje binárna maska pixelov, ktoré spadajú do tohto rozsahu~\cite{opencv2025}.\par
Výstup obsahuje šum a diery, ktoré môžu viesť k nesprávnym výsledkom, preto je ich nutné eliminovať. Tento efekt je možné dosiahnuť pomocou morfologických transformácií~\cite{opencv2025}.\par
Šum predstavuje malé izolované regióny pixelov, ktoré do obrazu nepatria. Morfologické otvorenie dokáže tento šum odstrániť -- v kóde je to realizované volaním funkcie \verb|morphologyEx| s argumentom \verb|MORPH_OPEN| a maticou jednotiek, ktorá funguje ako filter~\cite{opencv2025}.\par
Na uzavretie dier -- prazdnych miest vo vnútri objektu -- sa používa rovnaká funkcia, no v tomto prípade s argumentom \verb|MORPH_CLOSE|, čo predstavuje morfologické uzavretie~\cite{opencv2025}.\par
\begin{lstlisting}[language=Python, caption=Maskovanie tmavých regiónov]
def mask_road(frame):
    hsv = cv.cvtColor(frame, cv.COLOR_BGR2HSV)
    mask = cv.inRange(hsv, lower_black, upper_black)

    kernel = np.ones((5, 5), np.uint8)
    mask = cv.morphologyEx(mask, cv.MORPH_OPEN, kernel)
    mask = cv.morphologyEx(mask, cv.MORPH_CLOSE, kernel)

    return mask
\end{lstlisting}
Výstupné maskovanie silne závisí od externých faktorov, ako napríklad okolité osvetlenie. Obrázok \ref{fig:mask} zobrazuje možný výstup maskovania.\clearpage
\begin{figure}[!ht]
	\centering
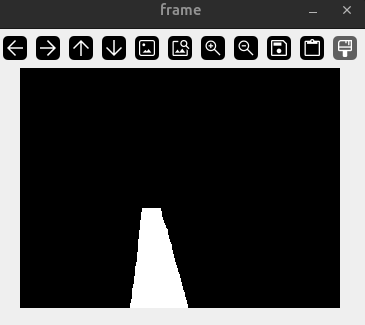
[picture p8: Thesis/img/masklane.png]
	
	\caption{Hľadanie tmavého jazdného pruhu.}
	\label{fig:mask}
\end{figure}
\subsubsection{Hľadanie kontúr vozovky}
Kontúry sú dôležitou súčasťou detekcie jazdných pruhov na vozovke. Princípom sa podobá hľadaním hranice tmavého objektu na svetlom pozadí~\cite{opencv2025}.\par
V knižnici OpenCV existuje funkcia \verb|findContours| na algoritmickú detekciu kontúr v obraze. Funkcia vracia dve polia --- výstupné pole kontúr a pole opisujúce hierarchiu topológie obrazu. Táto štruktúra sa však v ďalšom procese ignoruje, keďže pre danú aplikáciu nie je relevantná~\cite{opencv2025}.\par
Funkcia sa volá s dvomi parametrami. Prvým parametrom je režim vyhľadávania kontúr; využíva sa mód \verb|RETR_EXTERNAL|, ktorý zachytáva iba najpovrchovejšie vonkajšie kontúry. Alternatívne režimy zachytávajú všetky dostupné kontúry, no líšia sa v ich hierarchickom usporiadaní --- môže ísť o zoznam, dvojstupňovú alebo stromovú štruktúru~\cite{opencv2025}.\par
Druhý parameter predstavuje algoritmus aproximácie kontúr. V implementácii je využívaný režim \verb|CHAIN_APPROX_SIMPLE|. Z praktického hľadiska tento režim komprimuje segmenty bodov ležiace v jednej priamke --- horizontálne, vertikálne alebo diagonálne --- a ponecháva iba ich koncové body. To znamená, že štvorcová kontúra je zjednodušená iba na jej rohové body. Alternatívna metóda využíva algoritmus aproximácie pomocou Teh-Chinových reťazcov, zatiaľ čo iná ponecháva všetky body kontúry bez zmeny~\cite{opencv2025}.\par
Implementácia kódu v systéme detekcie čiar vyzerá nasledovne.\par
\begin{lstlisting}[language=Python, caption=Detekcia kontúr]
def find_contours(mask):
    contours, _ = cv.findContours(mask, cv.RETR_EXTERNAL, cv.CHAIN_APPROX_SIMPLE)
    return contours
\end{lstlisting}
\subsection{Detekcia prekážok}
Dôležitým pilierom bezpečnosti autonómnych vozidiel je schopnosť detekcie prekážok. V reálnom čase musí systém identifikovať a klasifikovať objekty na vozovke alebo v jej blízkosti, ako aj adekvátne na ne reágovať. Tento proces využíva dáta z rôznych senzorov na vyhodnotenie situácie. Na základe týchto dát dokáže \acrshort{av} objekt obísť alebo pred ním bezpečne zastaviť~\cite{badue2021}.\par
V tejto podkapitole si vysvetlíme použité metódy na detekciu prekážok.
\subsubsection{Ultrazvukový senzor}
Pri tejto implementácii sme použili ultrazvukový senzor na detekciu prekážok priamo pred vozidlom. Použitý HC-SR04 ultrazvukový senzor funguje ako vysielač, prijímač aj riadiaci obvod -- obrázok \ref{fig:ultrazvuk} ilustruje jeho funkciu.\par
\begin{figure}[!ht]
	\centering
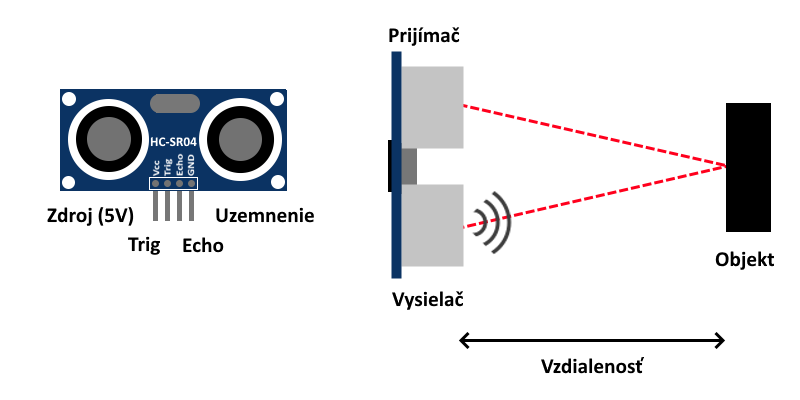
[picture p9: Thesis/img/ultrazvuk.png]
	
	\caption{Diagram fungovania ultrazvukového senzora}
	\label{fig:ultrazvuk}
\end{figure}
Princíp merania vzdialenosti je nasledovný:
\begin{enumerate}
	\item Arduino pošle signál vysokej úrovne na \verb|Trig| pin ultrazvukového senzora.
	\item Modul pošle osem 40 kHz signálov a nastaví vysokú úroveň na pine \verb|Echo|.
	\item Spustí sa časovač, zatiaľ čo senzor očakáva návratový signál.
	\item Ak zaznamená pulz, zastaví časovač a zníži hodnotu \verb|Echo| pinu.
\end{enumerate}
Na základe známej rýchlosti zvuku ($343~m*s^{-1}$) a času, za ktorý sa signál vrátil, je možné vypočítať vzdialenosť vozidla a objektu pred ním. Rovnica na výpočet vzdialenosti je nasledovná:
\[ \text{vzdialenosť} = \frac{\text{nameraný čas}}{2} \cdot \text{rýchlosť zvuku} \]\par
Ultrazvukový modul je riadený pomocou dvoch pinov mikrokontroléra Arduino. Jeden pin, nastavený na mód OUTPUT, sa používa na zaslanie vysokej hodnoty na modul. Druhý pin, nastavený na mód INPUT, je určený na získanie signálu zo senzora; na tento pin bola pripojená rutinu prerušenia.
\begin{lstlisting}[language=C++, caption=Obsluha prerušenia ultrazvukového senzora]
void IRAM_ATTR echoISR() {
  if (digitalRead(ECHO_PIN)) {
    echoStart = micros();
  } else {
    echoEnd = micros();
    echoDone = true;
  }
}
\end{lstlisting}
Keďže je tento výpočet náročnejší, merania prebiehajú v 50 ms intervaloch. Samotný výpočet sa vykonáva v rámci danej iterácie hlavného cyklu.
\begin{lstlisting}[language=C++, caption=Výpočet vzdialenosti z merania ultrazvukového senzora]
  if (echoDone) {
    uint32_t duration = echoEnd - echoStart;
    distance = duration / 58;
    echoDone = false;
  }
\end{lstlisting}
Z dôvodu zjednodušenia výpočtu sa používa aproximácia skutočnej vzdialenosti v centimetroch. Ak sa meraný predmet nachádza vo vzdialenosti do 10~cm, vozidlo zastaví~\cite{hcsr04}.
\subsubsection{Ultralytics YOLOv8}
V našej implementácii používame \acrshort{yolo}v8 od spoločnosti Ultralytics -- ako bolo popísané v sekcii \ref{subsubsec:yolo}. Pre programovací jazyk Python existuje jednoduché rozhranie, ktoré prácu s modelom zjednodušuje. Inštalácia prebehla pomocou správcu balíkov pip.\par
Nasledovný kód nám vytvorí inštanciu predtrénovaného modelu \verb|yolov8s.pt| a zadefinuje funkciu, pomocou ktorej vieme detegovať objekty.\clearpage
\begin{lstlisting}[language=Python, caption=Príprava CNN na detekciu objektov]
model = YOLO("yolov8s.pt")

def detect(frame):
    return model(frame, verbose=False)[0]
\end{lstlisting}
Funkcia \verb|detect| vracia zoznam (list) objektov \verb|Result|, napriek tomu, že vstupom je iba jedna snímka. Nultý prvok zoznamu obsahuje všetky detekcie pre daný obrázok.
\subsection{Interpretácia dát}
Správna interpretácia výstupných dát z jednotlivých modulov je dôležitá pre spoluprácu senzorov a pohybových systémov vozidla. V autonómnych autách túto úlohu plní modul plánovania a rozhodovania, ktorý spája subsystémy vnímania a samotného konania.\par
Ak bola kamera úspešne pripojená a je možné načítať jej obraz, prechádzame k jeho samotnému spracovaniu.\par
Implementáciu sme začali detekciou prekážok pomocou \acrshort{cnn}. Na zvýšenie výpočtovej efektivity programu sa táto detekcia spúšťa každých 6 snímok. Keďže model \acrshort{yolo}v8 dokáže detegovať až 80 rôznych tried objektov – vrátane tých, ktoré sa na vozovke bežne nevyskytujú – vybrala sa iba ich špecifická podmnožina, čím sa predchádza falošným pozitívam. Do tohto výberu boli zahrnutí ľudia, dopravné prostriedky a zvieratá.\par
V prípade, že model \acrshort{yolo} identifikuje objekt z definovaného zoznamu prekážok, systém následne vyhodnotí podmienky na zastavenie vozidla. Rozhodovací proces sa opiera o tri hlavné podmienky, ktoré boli stanovené na základe testovania a optimalizácie systému:
\begin{enumerate}
	\item \textbf{Trajektória} Prvým krokom je určenie pozície prekážky vzhľadom na jazdnú dráhu vozidla. Podmienka je splnená v prípade, že sa objekt nachádza v rámci definovanej hranice. Hranice sa zväčšujú podľa blízkosti objektu k vozidlu.
	\item \textbf{Blízkosť objektu} V druhom kroku určujeme vzdialenosť k objektu, ktorú aproximujeme na základe spodnej vertikálnej súradnice detegovanej prekážky.
	\item \textbf{Spoľahlivosť} Záverečná podmienka je overenie miery konfidencie modelu. Týmto sa minimalizujú falošné pozitíva a nežiadúce zastavenie vozidla.
\end{enumerate}
Až po súčasnom splnení všetkých troch podmienok sa aktivuje zastavenie vozidla.\clearpage
\begin{lstlisting}[language=Python, caption=Rozhodovanie zastavenia pri detekcii pomocou CNN]
def decide_stop(det, alpha = 0.5):
    for box in det.boxes:
        cls = int(box.cls[0])
        name = model.names[cls]

        if name in obstructions:
            x1, y1, x2, y2 = map(int, box.xyxy[0])

            conf = float(box.conf[0])
            margin = int(y2 * alpha)

            in_front = x1 < (CENTER + margin) and x2 > (CENTER - margin)
            close = y2 > CLOSE_THRESHOLD
            reliable = conf > CONF_THRESHOLD
            
            if in_front and close and reliable:
                return True, box
    return False, None
\end{lstlisting}
Posledný krok je zaznačiť detekciu na snímke -- viď obrázok \ref{fig:cnndetect}.\par
\begin{figure}[!ht]
	\centering
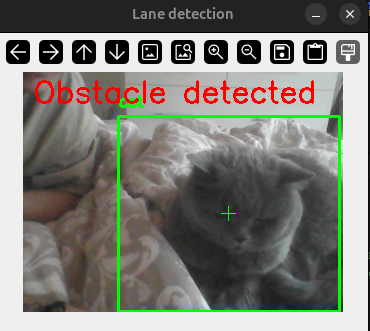
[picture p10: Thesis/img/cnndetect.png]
	
	\caption{Detekcia prekážky pomocou CNN.}
	\label{fig:cnndetect}
\end{figure}
V alternatívnom scenári, kde nebola nedetegovaná prekážka pomocou \acrshort{cnn}, postupujeme s určením jazdného pruhu.\par
Po identifikácii kontúr jazdného pruhu je ďalším krokom určenie stredovej línie tej najvýraznejšej z nich. Vyberieme si kontúru s najväčšou plochou. Pomocou funkcie \verb|moments| z knižnice OpenCV získame momenty -- vážené priemery intezity (jasu) -- jednotlivých pixelov. Tieto údaje sú dôležité pri výpočte geometrického stredu kontúry~\cite{opencv2025}.\par
Súradnice stredu ($c_x, c_y$) vypočítame pomocou nasledujúcich vzorcov:
\begin{itemize}
	\item \textbf{X-ová súradnica} $c_x=\frac{m_{10}}{m_{00}}$
	\item \textbf{Y-ová súradnica} $c_y=\frac{m_{01}}{m_{00}}$
\end{itemize}
Kde $m_{10}$ a $m_{01}$ predstavujú horizontálny a vertikálny moment a $m_{00}$ zodpovedá ploche danej kontúry.\par
\begin{lstlisting}[language=Python, caption=Výpočet geometrického stredu kontúry]
def find_center(contours):
    if contours:
        largest = max(contours, key=cv.contourArea)
        M = cv.moments(largest)
        if M["m00"] != 0:
            cx = int(M["m10"] / M["m00"])
            cy = int(M["m01"] / M["m00"])

            return cx, cy
    return None, None
\end{lstlisting}
Po zistení geometrického stredu jazdného pruhu bude vypočítaná samotná hodnota riadenia. Naša implementácia normalizuje hodnoty na rozsah hodnôt $<1, 511>$, čím zabezpečí plynulé vstupy pre riadiaci systém vozidla.\par
\begin{itemize}
	\item \textbf{Hodnoty $<1,255>$:} Otáčanie doľava.
	\item \textbf{Hodnoty $<257,511>$:} Otáčanie doprava.
	\item \textbf{Hodnota $256$:} Priama jazda.
	\item \textbf{Hodnota $0$:} Rezervovaná pre zastavenie.
\end{itemize}
Tento normalizovaný postup priraďuje odchýlku zo stredu priamo k hodnote riadenia. Aplikáciou nelineárnej mocninovej funkcie transformujeme výstupný rozsah tak, aby sme v okolí stredovej osi dosiahli vyššiu stabilitu a presnosť riadenia.\clearpage
\begin{lstlisting}[language=Python, caption=Výpočet hodnoty riadenia]
def compute_steering(cx, center=160, alpha=1.6):
    error = (cx - center) / center
    error = pow(abs(error), alpha) * (1 if error >= 0 else -1)

    return int(256 + error * 255)
\end{lstlisting}
Pomocou zistených hodnôt sa zaznačí stred jazdného pruhu a vypíše hodnota otáčania, ako je možné vidieť na obrázku \ref{fig:center}.\par
\begin{figure}[!ht]
	\centering
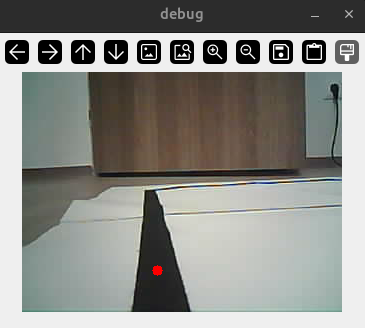
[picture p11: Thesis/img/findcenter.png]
	
	\caption{Hľadanie stredu jazdného pruhu.}
	\label{fig:center}
\end{figure}
Riadiaci program na platforme Arduino najskôr kontroluje údaje z ultrazvukového modulu. Ak senzor deteguje prekážku vo vzdialenosti do desiatich centimetrov, vozidlo okamžite zastaví. Tento ultrazvukový snímač má v celom systéme najvyššiu prioritu.\par
\begin{lstlisting}[language=Python, caption=Rozhodovanie na vozidle] 
if (distance < 10 || steer < -255 || steer > 255) {
  stopWheels();
} else {
  driveSteering(steer);
}
\end{lstlisting}
Celkovú postupnosť krokov v tejto podkapitole opisuje nasledovný sekvenčný diagram.\par
\begin{figure}[!ht]
	\centering
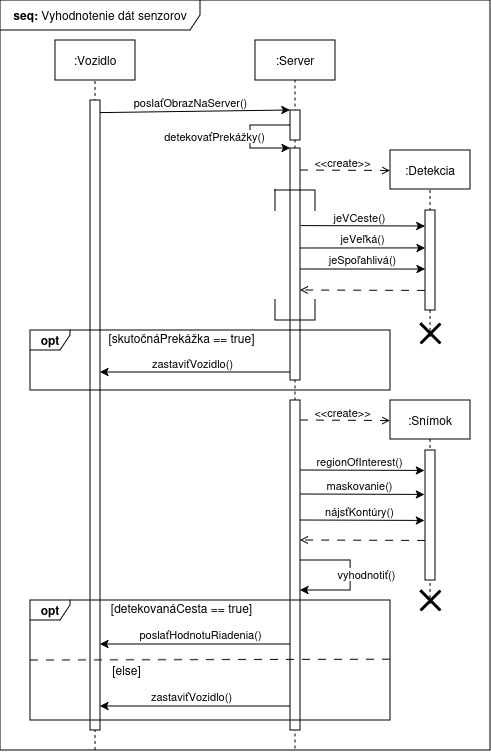
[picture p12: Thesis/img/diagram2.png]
	
	\caption{Sekvenčný diagram vyhodnotenia dát zo senzorov.}
	\label{fig:sequence}
\end{figure}
\clearpage
\subsection{Návrh komunikácie komponentov}
Komunikácia komponentov predstavuje dôležitý aspekt projektu, pretože je nutné aby si jednotlivé časti mohli synchrónne vymieňať a spracovať dáta.\par
Dôsledkom nízkeho výpočtového výkonu mikrokontrolérov Arduino sme použili v tejto implementácii model klient-server. V danej štruktúre vystupujú dva typy entít; nadradení klienti iniciujú požiadavky na pasívny server, ktorý posiela odpovede klientom.\par
\begin{figure}[!ht]
	\centering
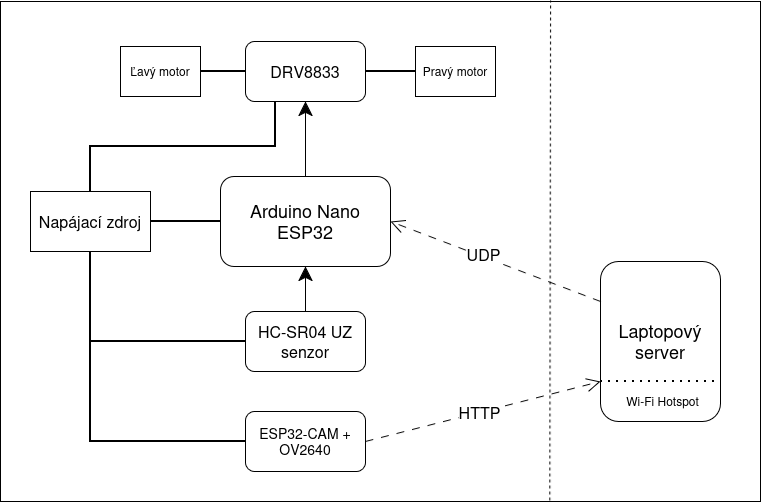
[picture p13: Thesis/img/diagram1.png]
	
	\caption{Diagram komunikácie komponentov}
	\label{fig:spojenie}
\end{figure}
\subsubsection{Komunikácia kamery a serveru}
Server je v našom projekte laptop, ktorý taktiež spúšťa Wi-Fi sieť na komunikáciu s komponentmi -- viď obrázok \ref{fig:spojenie}.\par
Všetky funkcie webového servera boli implementované v jazyku Python. Bezdrôtový prístupový bod bol vytvorený prostredníctvom nástroja NetworkManager, ktorý slúži na konfiguráciu sieťových rozhraní v operačnom systéme Linux. S jeho pomocou bola nakonfigurovaná sieťová karta laptopu do režimu Wi-Fi hotspotu. Na spustenie tohto systémového nástroja priamo z Pythonu bola využitá knižnica subprocess.\clearpage
\begin{lstlisting}[language=Python, caption=Zapnutie Wi-Fi hotspotu]
SSID = "LAPTOP_AP"
PASSWORD = "12345678"

def startHotspot():
    print("Starting Hotspot")
    subprocess.run([
        "nmcli",
        "device",
        "wifi",
        "hotspot",
        "ssid", SSID,
        "password", PASSWORD
    ], check=True)
\end{lstlisting}
Pred spustením cyklu spracovania obrazu bolo nutné počkať na pripojenie kamerového modulu k Wi-Fi sieti. Dostupnosť bola zisťovaná cez protokol ICMP vysielaním ping paketov v 1-sekundových intervaloch. Výstup s hodnotou 0 potvrdzuje úspešné pripojenie kamery.\par
\begin{lstlisting}[language=Python, caption=Pingovanie IP adresy kamerového modulu]
def ping_cam():
    while True:
        response = os.system(f"ping -c 1 {CAM_IP} > /dev/null 2>&1")
        if response == 0:
            print("ESP32-CAM online")
            return
        print(".", end="")
        time.sleep(1)
\end{lstlisting}
Modul ESP32-CAM pracuje v režime klienta, ktorý prostredníctvom Wi-Fi siete odosiela obrazové dáta na server. Po nadviazaní spojenia začne cez protokol HTTP na porte 81 vysielať video stream z kamery OV2640. Snímky sú prenášané v rozlíšení QVGA (320 × 240 pixelov) vo formáte JPEG. Nová snímka sa odosiela každých 30 ms, vďaka čomu dosahuje výsledný stream snímkovú frekvenciu približne 30 FPS.\clearpage
\begin{lstlisting}[language=C++, caption=Spustenie HTTP stream na ESP32-CAM]
void startCameraServer(){
  httpd_config_t config = HTTPD_DEFAULT_CONFIG();
  config.server_port = 81; // port streamu
  
  if(httpd_start(&stream_httpd, &config) == ESP_OK){
    httpd_uri_t stream_uri = {
      .uri       = "/stream",
      .method    = HTTP_GET,
      .handler   = stream_handler,
      .user_ctx  = NULL
    };
    httpd_register_uri_handler(stream_httpd, &stream_uri);
  }
}
\end{lstlisting}
\subsubsection{Komunikácia serveru a mikrokontroléra}
Vďaka statickej IP adrese bolo možné určiť, na ktorej URL má server očakávať obrázky. Na ich načítanie slúži funkcia VideoCapture z OpenCV, ktorá podporuje spracovanie obrazu z URL. Po analýze dát server odošle inštrukcie pre Arduino Nano. Odpoveď sa posiela cez UDP socket na port 5005 mikrokontroléra, čo je optimálne pre aplikácie v reálnom čase. Komunikáciu zabezpečuje knižnica socket v Pythone a posielané dáta majú veľkosť len 2 bajty, čo je najmenší nutný buffer na uloženie informácií o riadení.\par
\begin{lstlisting}[language=Python, caption=Posielanie UDP packetov]
CAM_IP = "10.42.0.128"
CAM_URL = f"http://{CAM_IP}:81/stream"

UDP_IP = "10.42.0.111"
UDP_PORT = 5005

sock = socket.socket(socket.AF_INET, socket.SOCK_DGRAM)

def sendUDP(direction: float):
    sock.sendto(struct.pack('<H', direction), (UDP_IP, UDP_PORT))
\end{lstlisting}
\subsubsection{Komunikácia mikrokontroléra s perifériami}
Arduino príjme UDP packet a súčasne získa nameranú vzdialenosť z ultrazvukového senzora. Keďže Echo pin na senzore, z ktorého získavame signál, má výstupné napätie 5~V, je potrebné ho znížiť na 3,3~V, čo je operačné napätie všetkých \acrshort{gpio} pinov mikrokontroléra.\par
Toto bolo dosiahnuté pomocou deliča napätia. Výstupné napätia deliča bolo vypočítané pomocou rovnice $V_{OUT} = \frac{V_{IN} \cdot R_2}{R_1 + R_2}$, kde $R_1$ a $R_2$ sú odpory dvoch rezistorov zapojených sériovo, $V_{IN}$ je vstupné napätie a $V_{OUT}$ výstupné napätie. Bolo určené, že je potrebné zapojiť $10 \,k\Omega$ a $20 \,k\Omega$ odpor v sérii.\par
Ultrazvukový snímač sa spúšťa v intervaloch 50ms, z dôvodu efektívneho využitia výpočtového výkonu. Jednotlivé spustenia sú vo forme vyvolania prerušenia.\par
Každému z motorčekov sú priradené dva výstupné piny -- pinA a pinB. Všetky štyri piny sú pripojené na osobitný PWM kanál. Pulse Width Modulation (PWM) nám dovoľuje presnú kontrolu nad rýchlosťou motorčekov. Kanály boli nakonfigurované pomocou funkcie \verb|ledcSetup|. V danej funkcii bola nastavená frekvencia menenia (\verb|PWM_FREQ|) na 20kH a rozlíšenie (\verb|PWM_RES|) na 8. Takéto rozlíšenie dovoľuje 256 ($2^8$) rôznych stupňov rýchlosti. Následne boli funkciou \verb|ledcAttachPin| priradené piny ku kanálom.\par
Signály z pinov sú privedené na DRV8833, ktorý fyzicky riadi dva \acrshort{dc} motory. Na tento účel bola využitá funkcia \verb|ledcWrite| z knižnice Arduino určenej pre mikrokontroléry ESP32. V prípade, že má motor sa otáčať vpred, na pin A sa zapíše hodnota rýchlosti a pin B sa nastaví na nulu. V opačnom scenári sa stavy pinov vymenia. Ak je potrebné motor zastaviť, na oba piny sa zapíše hodnota 0, pričom rovnaký efekt by sa dosiahol aj zápisom vysokých hodnôt na oba piny súčasne.\par
\begin{lstlisting}[language=C++, caption=Vnútorný cyklus Arduina]
void loop() {
  while (udp.parsePacket() >= 2) {
    udp.read(incoming, 2);

    uint16_t raw = incoming[0] | (incoming[1] << 8);
    steer = (int)raw - 256;
  }

  static unsigned long lastTrig = 0;
  if (millis() - lastTrig > 50) {
    lastTrig = millis();
    echoDone = false;
    triggerUltrasonic();
  }

  if (echoDone) {
    uint32_t duration = echoEnd - echoStart;
    distance = duration / 58;
    echoDone = false;
  }
}
\end{lstlisting}
\subsection{Návrh rámu a rozloženie komponentov}
Správny návrh rámu a rozloženia komponentov na ňom je dôležitý pre správne fungovanie celého systému. V našej implementácii sme sa zamerali na minimalizovanie hmotnosti vozidla a maximalizovanie kompaktnosti komponentov, a tým ich zohranie.\par
Na návrh rámu sme použili softvér Blender -- populárny, všeobecne používaný program na dizajn, modelovanie a animáciu, ktorý umožňuje exportovať do formáte .stl, ideálneho pre 3D tlač. Po odmeraní všetkých komponentov, sme začali pracovať na prototype rámu.\par
V procese vývoja bolo vyskúšaných viacero návrhov, v rámci ktorých bolo testované rôzne usporiadania a orientácie jednotlivých súčiastok. Napokon bol zvolený dizajn s dvoma kolesami vpredu a vymeniteľnou zadnou vidlicou, ktorú je možné v prípade opotrebovania alebo zmeny povrchu jednoducho nahradiť.\par
Najťažšie komponenty -- konkrétne batériu a menič napätia – sme umiestnili na spodnú stranu vozidla s cieľom znížiť ťažisko a zvýšiť celkovú stabilitu. Konštrukciu sme zároveň doplnili o držiak na kameru a ultrazvukový senzor na zabezpečenie stabilizácie obrazu.\par
\begin{figure}[!ht]
	\centering
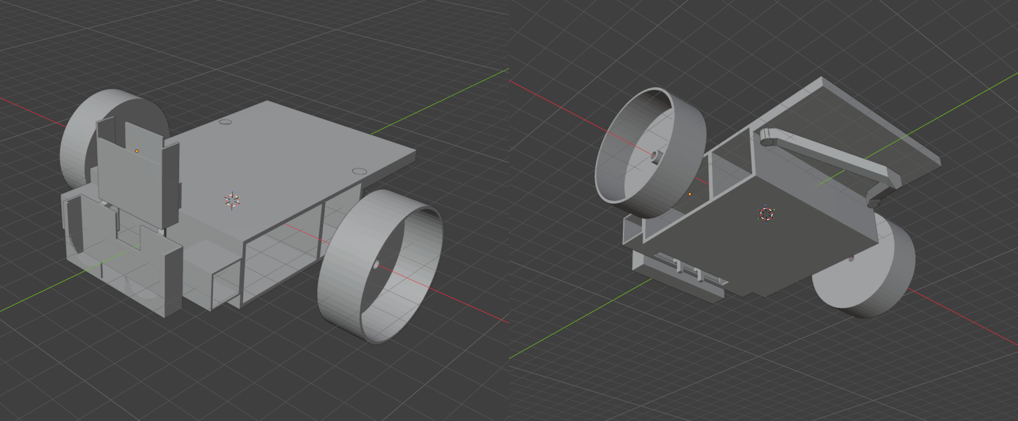
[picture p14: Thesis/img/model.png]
	
	\caption{3D model vozidla}
	\label{fig:model}
\end{figure}
Model bol vytlačený na tlačiarni Bambulab A1 mini, použitím filamentu kyseliny polymliečnej (PLA). Prvotne boli kolesá vytlačené z polyetyléntereftelátu (PET) a doplnené o protišmykový polep, no tento povrch nedosahoval požadovaný stupeň trakcie.\par
Zakúpili sme dve kolesá s priemerom 43mm, gumeným povrchom a oskou určenou pre náš typ motorčekov.\par
\subsection{Montovanie vozidla a nahratie softvéru}
V tejto podkapitole si priblížime fyzické spojenie hardvéru a softvéru. Priebeh procesu nebol priamočiary a vykazoval časové aj logické odchýlky od predpokladaného modelu. Mnohé spomenuté komponenty boli testované samostatne a skutočný program prešiel mnohými iteráciami, predtým než sme našli tú ideálnu. Pre potreby tejto práce však uvádzame optimálnu sekvenciu krokov, ktoré predstavujú logicky správny postup.\par
Začali sme nahratím kódu na Arduino Nano ESP32. Tento mikrokontrolér má podporu nahrávania kódu pomocou konektoru USB-C. Integrované vývojové prostredie Arduino IDE (obrázok \ref{fig:arduinoide}) automaticky detegovalo pripojený mikrokontrolér. Pomocou tlačidla \verb|Upload| v tomto prostredí bol úspešne skompilovaný a nahratý kód do pamäte Arduina.\par
\begin{figure}[!ht]
	\centering
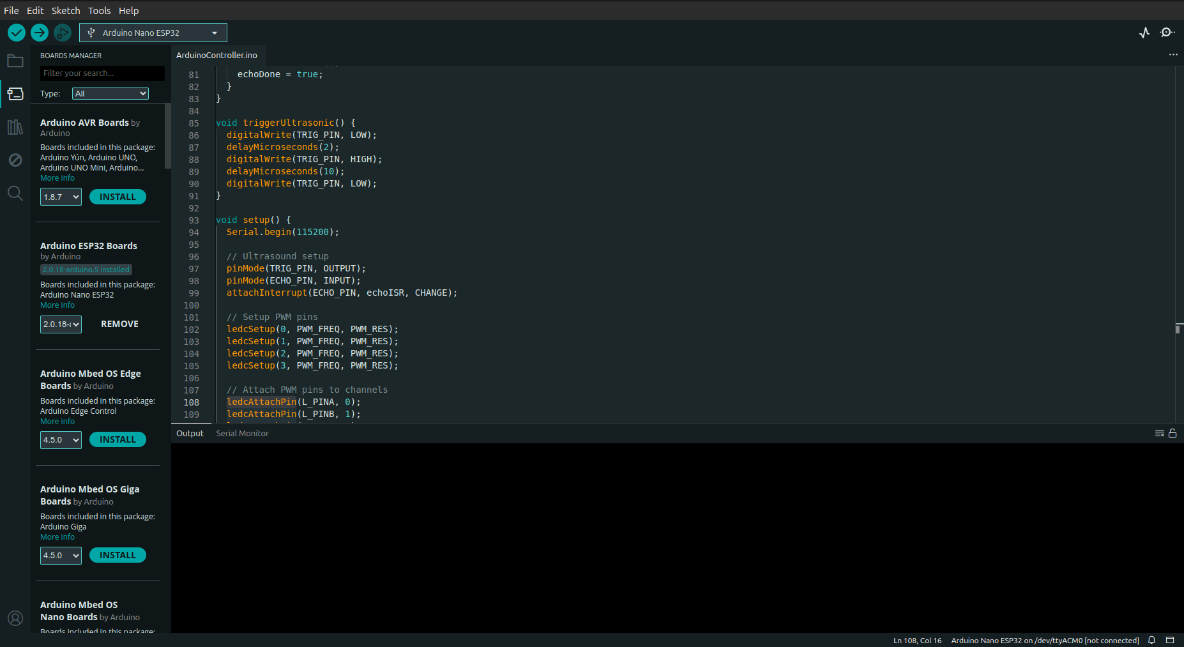
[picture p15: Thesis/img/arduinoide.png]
	
	\caption{Integrované vývojové prostredie Arduino}
	\label{fig:arduinoide}
\end{figure}
V ďalšom kroku bol nahratý kód na ESP32-CAM. Na rozdiel od Arduina, ESP32-CAM nemá integrovaný USB konektor. Na tento účel bol k nemu pripojený programovací shield určený pre túto dosku. Tento modul funguje ako adaptér USB na sériové rozhranie a disponuje starším Micro-USB portom. Podobne ako v minulom kroku, Arduino IDE rozpoznalo vývojovú dosku a kód bol pomocou tohto prostredia skompilovaný a nahratý. Týmto krokom je nahrávanie softvéru pre hardvérovú časť vozidla hotové.\par
Na prepojenie súčiastok sme použili nepájivé pole a farebne odlíšené vodiče. Breadboard bol pripevnený na rám vozidla pomocou lepiacej vrstvy na jeho spodnej strane.\par
Vďaka headerom bolo Arduino Nano ESP32 a driver motorov DRV8833 zapojené priamo do breadboardu.\par
Podľa konfigurácie boli prepojené štyri výstupné piny Arduina pre ľavý a pravý motor s IN pinmi driverom motorov. K motorom boli prispájkané káble a pripevnené kolesá. Celá sústava pre obe strany bola následne zasunutá do vyhradených držiakov. Konce týchto káblov sme zapojili do OUT pinov drivera motorov.\par
V ďalšom kroku bol zapojený ultrazvukový senzor. Trig pin senzora bol spojený s určeným výstupným pinom na Arduine pomocou vodiča. Na Echo pin senzora bol pripojený $10 \,k\Omega$ rezistor a $20 \,k\Omega$ rezistor bol zapojený cez spoločné uzemnenie. Výstupné napätie 3,333 V – prijateľné pre Arduino – bolo vyvedené z vodiča pripojeného medzi týmito dvoma odpormi. Koniec tohto vodiča bol zapojený do vstupného pinu na Arduine -- viď obrázok \ref{fig:voltagedivider}.\par
\begin{figure}[!ht]
	\centering
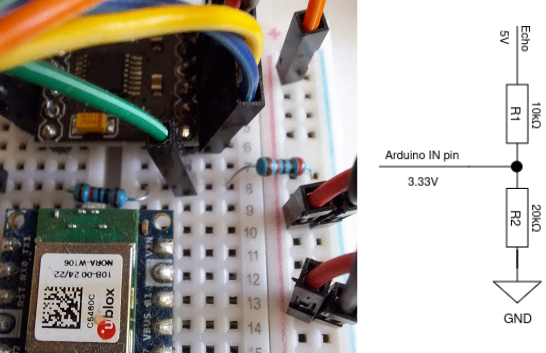
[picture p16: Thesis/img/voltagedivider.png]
	
	\caption{Delič napätia}
	\label{fig:voltagedivider}
\end{figure}
Ultrazvukový senzor a kamerový modul boli vložené do držiaka. Následne bol držiak nasadený na dva podporné body nachádzajúce sa na ráme vozidla. Pomocou sťahovacích pások bol držiak pripevnený.\par
V ďalšom kroku bola zapojená batéria. Na vodič kladného pólu batérie bol pripevnený vypínač a následne boli oba káble zapojené do buck meniča. K výstupnému portu meniča bol pripojený modifikovaný USB kábel, ktorého koncový konektor bol odstránený. K jeho červenému a čiernemu vodiču boli pripevnené kontakty -- kladný a záporný. Tento upravený konektor bol potom zapojený do napájacej koľajnice breadboardu.\par
Mikrokontrolér, kamerový modul, motor driver a ultrazvukový senzor boli zapojené na napájaciu koľajnicu pomocou čiernych a červených káblikov.\par
Na záver bola do rámu vložená podporná vidlica, čím bola montáž vozidla skompletizovaná -- viď obrázok \ref{fig:vozidlo1} a \ref{fig:vozidlo2}.\par
\begin{figure}[!ht]
	\centering
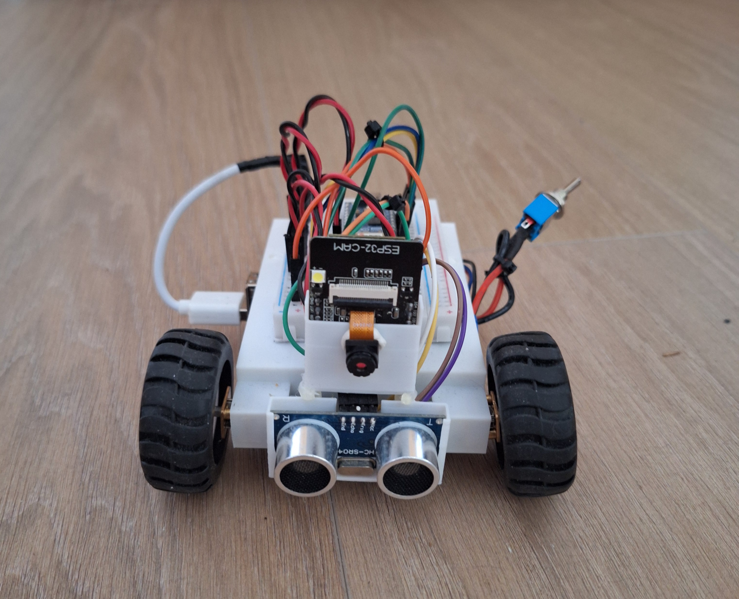
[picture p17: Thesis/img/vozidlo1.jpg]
	
	\caption{Skompletizované vozidlo (predok)}
	\label{fig:vozidlo1}
\end{figure}
\begin{figure}[!ht]
	\centering
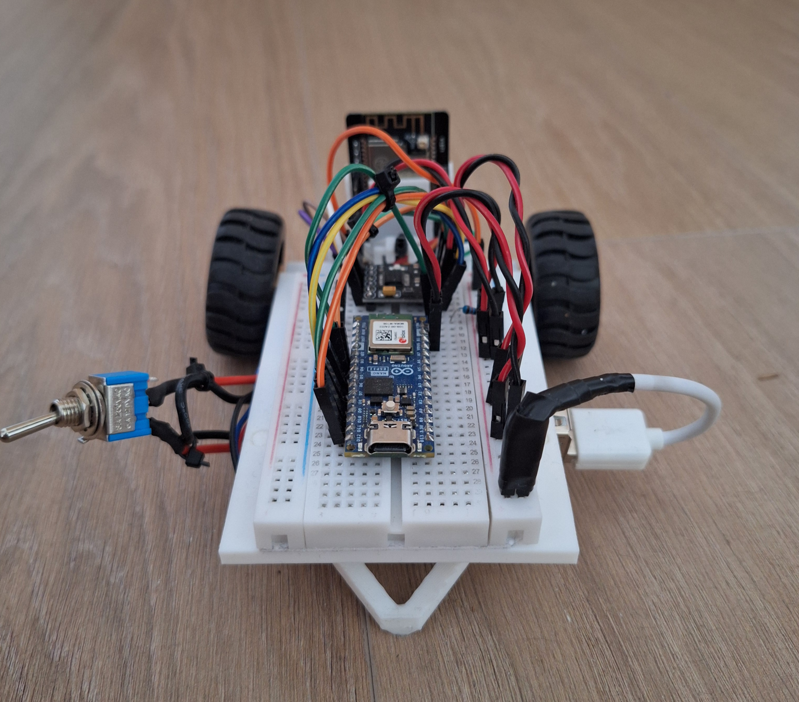
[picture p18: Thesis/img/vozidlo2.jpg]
	
	\caption{Skompletizované vozidlo (zadok)}
	\label{fig:vozidlo2}
\end{figure}

\clearpage
\section{Metodika testovania}\label{sec:MetodikaTestovania}
V tejto kapitole sú popísané použité techniky a proces testovania navrhnutého systému. Testovanie je nevyhnutnou súčasťou realizácie každého projektu, pretože umožňuje overiť funkčnosť návrhu v praxi a posúdiť mieru naplnenia stanovených cieľov v reálnych podmienkach. Výsledky tejto časti zároveň slúžia na porovnanie dosiahnutých riešení s inými prácami, ktoré využívajú odlišnú architektúru.\par
V rámci experimentov sme sa zamerali na overenie dvoch hlavných funkcií systému:
\begin{itemize}
	\item \textbf{Autonómne riadenie} Cieľom bolo otestovať schopnosť vozidla sledovať vopred určenú trasu. Testovacia dráha bola navrhnutá tak, aby obsahovala rovné úseky aj zákruty. Úspešnosť systému sme hodnotili podľa času dokončenia a schopnosti vozidla udržať sa na vozovke bez vybočenia.
	
	\item \textbf{Detekcia prekážky} Keďže vývoj tohto systému bol hlavným cieľom práce, väčšina testov je zameraná práve na túto oblasť. Systém využíva dva typy senzorov -- kamerový modul s konvolučnou neurónovou sieťou a ultrazvukový senzor. Testy sú navrhnuté tak, aby preverili spoľahlivosť oboch týchto systémov.
\end{itemize}
\subsection{Autonómne riadenie}
Autonómne riadenie chápeme, ako schopnosť vozidla samostatne vykonávať jazdné úkony bez zásahu ľudského operátora. Pre overenie tejto schopnosti musí riadiaci systém vozidla zvládať jazdu nielen na priamych úsekoch, ale aj v zákrutách. Z tohto dôvodu bolo nevyhnutné navrhnúť testovaciu dráhu, ktorá zahŕňa obidva prvky. Grafický návrh trate bol pôvodne vypracovaný v prostredí editora obrázkov.\par
Po grafickom návrhu nasledovala fyzická realizácia trate. Na jej vytvorenie sme použili osem papierov formátu A4 (celkovou plochou zodpovedajúcich formátu A1), ktoré boli vzájomne prepojené do súvislého celku. Samotná dráha bola následne vytvorená pomocou čiernej matnej lepiacej pásky, pričom sme ako presnú predlohu využili digitálny dizajn (obrázok \ref{fig:track}).\clearpage
\begin{figure}[!ht]
	\centering
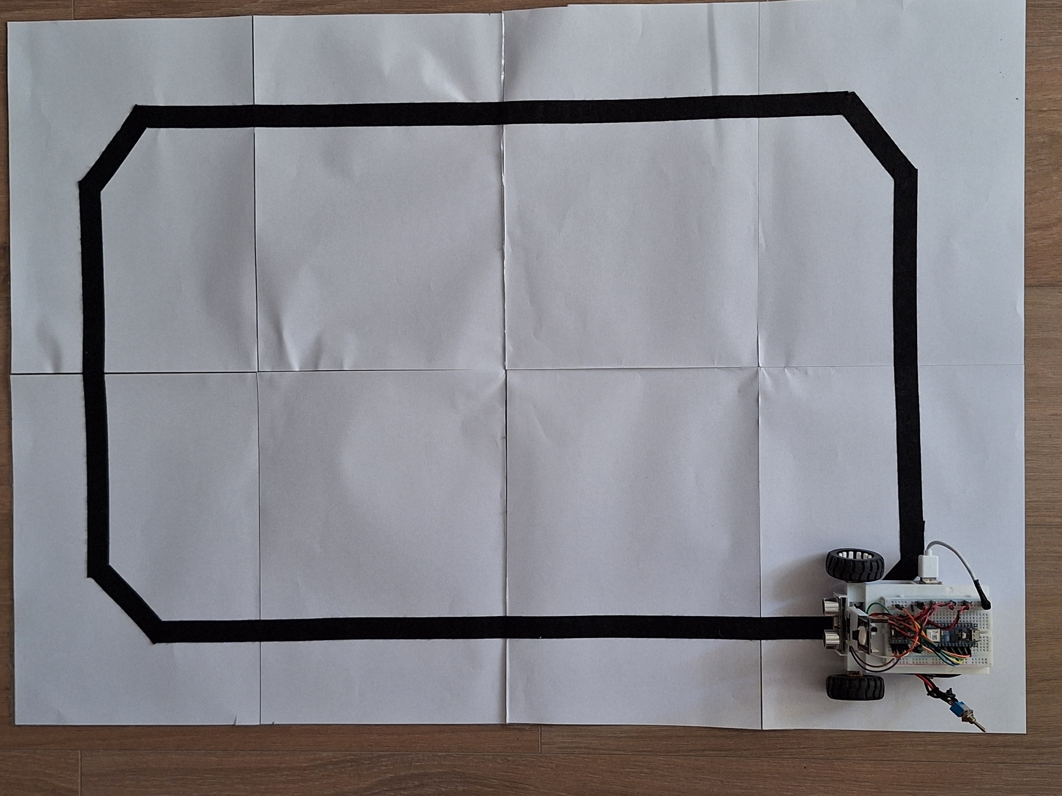
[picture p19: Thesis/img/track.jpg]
	
	\caption{Testovacia trať}
	\label{fig:track}
\end{figure}
Proces testovania spočíva v sledovaní dvoch hlavných parametrov: schopnosti vozidla prejsť celú dráhu bez jej opustenia a času, za ktorý okruh absolvuje. Meranie prebiehalo v interiérových podmienkach pri ambientnom dennom svetle. Čas prejazdu vozidla cez stanovenú dráhu sme merali od momentu prvotného pohybu až po opätovné prekročenie štartovacej čiary (dokončenie okruhu).\par
Pri testovaní sme sledovali aj chybovosť, konkrétne nedokončenie dráhy. Tento jav sme definovali v dvoch prípadoch:
\begin{itemize}
	\item ak sa vozidlo permanentne zastavilo v dôsledku straty detekcie vodiacej čiary,
	\item ak vozidlo opustilo jazdný pruh z dôvodu chybnej detekcie objektov mimo dráhy.
\end{itemize}
V rámci tohto testu detekciu prekážok sme nesledovali. Prípadné zastavenie sa preto nepovažovalo za chybu a test bol zopakovaný.\par
Test sme vykonali celkovo desaťkrát. Všetky namerané výsledky zaznamenali do tabuľky, aby sme mohli následne vyhodnotiť úspešnosť a stabilitu riadenia.
\subsection{Detekcia prekážky}
Významnou vlastnosťou autonómneho riadenia je schopnosť vozidla detegovať prekážky a vhodne na ne reagovať. Väčšina systémov využíva určitú mieru redundancie, čo znamená, že vozidlo disponuje záložným riešením pre prípad zlyhania niektorého z podsystémov.\par
Z tohto dôvodu sme testovanie rozdelili do dvoch častí:
\begin{itemize}
	\item Testovanie ultrazvukového modulu.
	\item Testovanie konvolučnej neurónovej siete.
\end{itemize}
Na obrázku \ref{fig:us_obstacles} sú znázornené objekty využité pri testovaní ultrazvukového senzoru.\par
\begin{figure}[!ht]
	\centering
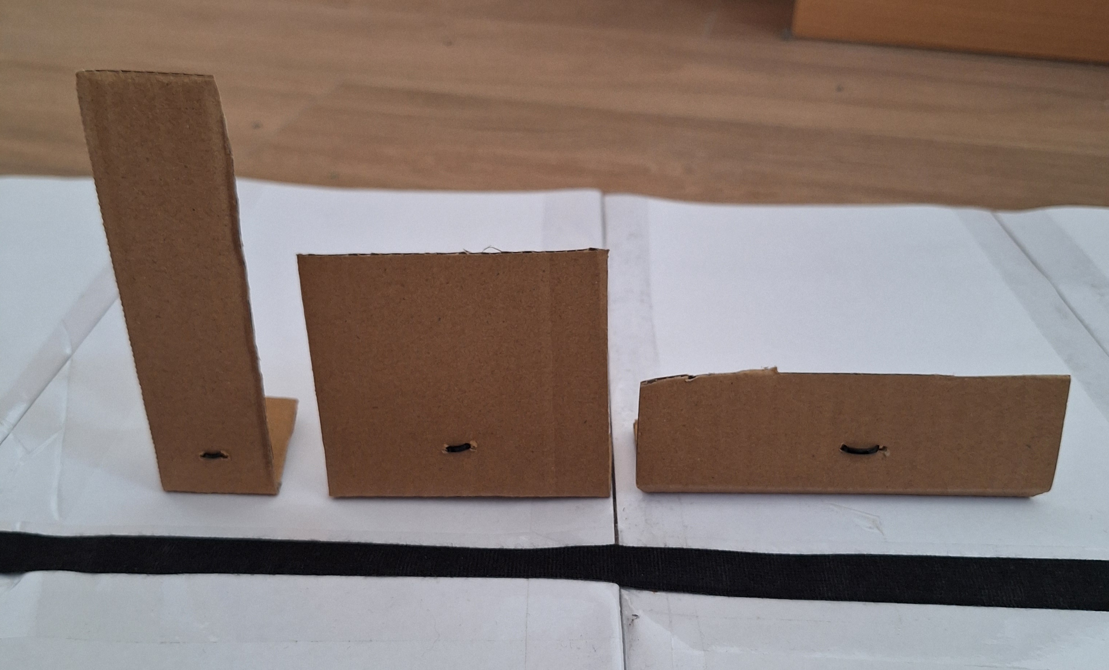
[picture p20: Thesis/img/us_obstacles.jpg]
	
	\caption{Prekážky na testovanie ultrazvukového modulu.}
	\label{fig:us_obstacles}
\end{figure}
Konkrétne ide o tieto typy prekážok:
\begin{itemize}
	\item \textbf{Štíhla prekážka} (4x14~cm): Slúži na zobrazenie prekážok s vertikálnou orientáciou, ako sú napríklad stĺpy alebo ľudia.
	\item \textbf{Stredne veľká prekážka} (9x9~cm): Predstavuje univerzálny typ objektu a reprezentuje rozmerovo priemerné prvky prostredia, napríklad časti stien či vozidiel.
	\item \textbf{Široká prekážka} (14x4~cm): Je určená na zobrazenie nízkych prekážok s horizontálnou orientáciou, kam môžeme zaradiť nízke oplotenie, menšie zvieratá alebo deti.
\end{itemize}
Proces testovania bol rozdelený do troch fáz podľa umiestnenia prekážky vzhľadom na jazdnú dráhu:\clearpage
\begin{itemize}
	\item \textbf{Fáza 1:} Prekážka je umiestnená priamo v strede vozovky.
	\item \textbf{Fáza 2:} Prekážka sa nachádza na okraji vozovky.
	\item \textbf{Fáza 3:} Prekážka je situovaná mimo vozovky.
\end{itemize}
V každej z týchto fáz sme sledovali a vyhodnocovali reakciu vozidla, konkrétne jeho schopnosť včas zastaviť, respektíve pokračovať v jazde v závislosti od polohy detegovaného objektu. Každý test sme opakovali päťkrát, čím sme získali celkovo štyridsaťpäť meraní.\par
Testovanie neurónovej siete prebiehalo s piatimi rôznymi objektmi: osobným automobilom, nákladným vozidlom, bicyklom, človekom a psom (obrázok \ref{fig:cnn_obstacles}). Na testovanie sme použili \acrshort{cnn} \acrshort{yolo}v8 od spoločnosti Ultralytics. Sledovali sme nielen úspešnosť detekcie, ale aj to, či systém správne vyhodnotí polohu prekážky (priamo na vozovke alebo v jej blízkosti) a adekvátne na ňu zareaguje. Ultrazvukový senzor sme odpojili, aby jeho vstup neovplyvňoval výsledky neurónovej siete. Každú situáciu sme testovali päťkrát, čo pri kombinácii typu objektu a jeho polohy prinieslo spolu päťdesiat výsledkov.\par
\begin{figure}[!ht]
	\centering
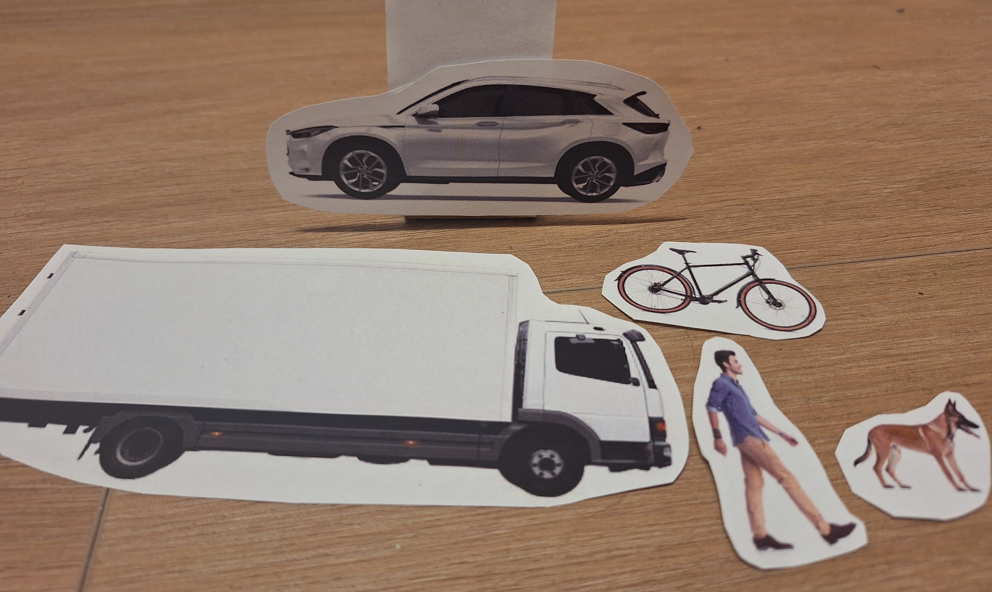
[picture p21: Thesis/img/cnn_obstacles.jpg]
	
	\caption{Prekážky na testovanie CNN.}
	\label{fig:cnn_obstacles}
\end{figure}
Celkovo v tejto časti vyhodnocujeme deväťdesiatpäť testovacích scenárov. Na ich základe určíme efektivitu navrhnutej implementácie a identifikujeme prípadné nedostatky systému detekcie prekážky.

\section{Výsledky}\label{sec:Vysledky}
V tejto kapitole sa zameriavame na analýzu dát získaných počas meraní opísaných v predchádzajúcej časti práce. Cieľom objektívneho zhodnotenia je získať relevantnú spätnú väzbu o úspešnosti navrhnutej implementácie. Namerané údaje zároveň slúžia ako podklad pre prípadné porovnanie s inými modelmi autonómnych vozidiel.\par
Proces vyhodnocovania sme rozdelili do troch častí, ktoré predstavujú jednotlivé systémy riadenia:
\begin{itemize}
	\item Testovanie detekcie vozovky.
	\item Testovanie ultrazvukového senzora.
	\item Testovanie konvolučnej neurónovej siete.
\end{itemize}
\subsection{Testovanie detekcie vozovky}
\setcounter{table}{0}
\begin{table}[!ht]
\caption{Detekcia jazdného pruhu}
\label{tab:detekcia}
\centering
\begin{tabular}{ | l | c | c | }
	\hline
	\textbf{Poradie} & \textbf{Čas} & \textbf{Nedokončilo?} \\
	\hline
	1 & 11.88 s & nie \\
	2 & 12.35 s & nie \\
	3 & n/a	& áno \\
	4 & 13.13 s & nie \\
	5 & 13.80 s & nie \\
	6 & 12.48 s & nie \\
	7 & 14.84 s & nie \\
	8 & 12.89 s & nie \\
	9 & 11.92 s & nie \\
	10 & 11.38 s &	nie \\
	\hline
	\textbf{Priemer} & 12.74 s & 90\% \\
	\hline
\end{tabular}
\end{table}
Tabuľka \ref{tab:detekcia} zobrazuje výsledky testovania detekcie jazdného pruhu. Z desiatich testov bolo deväť úspešných, kde vozidlo neopustilo trať. V treťom teste sme zaznamenali zlyhanie, kedy vozidlo pri zatáčaní stratilo vizuálny kontakt s jazdným pruhom. Vozidlo nedokázalo znovu detegovať vozovku, a preto sme test označili ako neúspešný.\par
Priemerný čas dosiahol 12.74 s, pričom medián bol 12.48 sekundy. Rozmedzie výsledkov bolo 3.46 sekúnd. Najrýchlejší prejazd sme zaznamenali v desiatom pokuse (11.38 s). Najpomalší čas bol v siedmom pokuse (14.84 s). Tento údaj je významný, keďže vozidlo v dôsledku dočasnej straty detekcie pruhu zastalo, čo predĺžilo prejazd o viac než dve sekundy oproti priemeru.\par
Vozidlo dokáže spoľahlivo nasledovať jazdný pruh na rovných úsekoch, no pri zabáčaní môže dôjsť k strate trajektórie. Vizuálny šum z kamery spolu s vysokou rýchlosťou otáčania môže vyvolať nadmernú korekciu, alebo naopak nedostatočnú reakciu riadenia, čo vedie k opusteniu jazdného pruhu. V reálnych podmienkach využíva vozidlo ďalšie vizuálne pomôcky na predvídanie takýchto situácií, napríklad dopravné značenie.
\subsection{Testovanie ultrazvukového senzora}
\begin{table}[!ht]
\caption{Ultrazvukový senzor (stred vozovky)}
\label{tab:ultrazvuk1}
\centering
\begin{tabular}{|l r|c|c|c|}
        \hline
        \multicolumn{2}{|c|}{} & \multicolumn{3}{c|}{\textbf{Zastavilo?}} \\ \hline
        \multicolumn{2}{|c|}{\textbf{Poradie}} & Štíhla & Stredná & Široká \\ \hline
        & 1 & áno & áno & áno \\ \hline
        & 2 & áno & áno & áno \\ \hline
        & 3 & áno & áno & áno \\ \hline
        & 4 & áno & áno & áno \\ \hline
        & 5 & áno & áno & áno \\ \hline
        \multicolumn{2}{|l|}{\textbf{Úspešnosť}} & 100.00\% & 100.00\% & 100.00\% \\ \hline
\end{tabular}
\end{table}
Tabuľka \ref{tab:ultrazvuk1} hodnoty namerané pri umiestnení prekážky na stred vozovky. Ultrazvukový senzor nemal problém detegovať prekážku a zastaviť 10~cm pred ňou.\par
\begin{table}[!ht]
\caption{Ultrazvukový senzor (mimo vozovky)}
\label{tab:ultrazvuk2}
\centering
\begin{tabular}{|l r|c|c|c|}
        \hline
        \multicolumn{2}{|c|}{} & \multicolumn{3}{c|}{\textbf{Zastavilo?}} \\ \hline
        \multicolumn{2}{|c|}{\textbf{Poradie}} & Štíhla & Stredná & Široká \\ \hline
        & 1 & nie & nie & nie \\ \hline
        & 2 & nie & nie & nie \\ \hline
        & 3 & nie & nie & nie \\ \hline
        & 4 & nie & nie & nie \\ \hline
        & 5 & nie & nie & nie \\ \hline
        \multicolumn{2}{|l|}{\textbf{Úspešnosť}} & 100.00\% & 100.00\% & 100.00\% \\ \hline
\end{tabular}
\end{table}
Podobne ako v predošlom teste, vozidlo nedetegovalo, že prekážka je v dráhe vozidla a správne vyhodnotilo, že nie je potrebné zastaviť vozidlo. Výsledky je možné vidieť v tabuľke \ref{tab:ultrazvuk2}.\par
\begin{table}[!ht]
\caption{Ultrazvukový senzor (pri vozovke)}
\label{tab:ultrazvuk3}
\centering
\begin{tabular}{|l r|c|c|c|}
        \hline
        \multicolumn{2}{|c|}{} & \multicolumn{3}{c|}{\textbf{Zastavilo?}} \\ \hline
        \multicolumn{2}{|c|}{\textbf{Poradie}} & Štíhla & Stredná & Široká \\ \hline
        & 1 & nie & nie & nie \\ \hline
        & 2 & nie & nie & nie \\ \hline
        & 3 & nie & nie & nie \\ \hline
        & 4 & nie & nie & nie \\ \hline
        & 5 & nie & nie & nie \\ \hline
        \multicolumn{2}{|l|}{\textbf{Úspešnosť}} & 0.00\% & 0.00\% & 0.00\% \\ \hline
\end{tabular}
\end{table}
Tabuľka \ref{tab:ultrazvuk3} zobrazuje kritické zlyhanie systému, ktoré priamo vyplýva z jeho technického návrhu. Ultrazvukové senzory sú primárne určené na detekciu objektov na krátke vzdialenosti pri nízkych rýchlostiach (napr. parkovacie manévre) a nie sú vhodné na všeobecnú detekciu prekážok. Pri reálnych automobiloch je tento nedostatok vyrovnaný rozmiestnením senzorov po celom obvode vozidla.\par
Použitý ultrazvukový modul HC-SR04 disponuje meracím uhlom 15°. Pri uplatnení sínusovej vety a stanovení brzdnej vzdialenosti na 10~cm od senzora možno vypočítať, že efektívny priemer základne detekčného kužeľa dosahuje približne 2,6~cm. Pre pokrytie celej čelnej šírky vozidla (11~cm) by bolo nevyhnutné zvýšiť detekčnú vzdialenosť až na 42~cm. Takéto nastavenie by však spôsobovalo predčasné zastavenie vozidla a vnášalo do systému nežiaduce falošné detekcie.
\subsection{Testovanie konvolučnej neurónovej siete}
\begin{table}[!ht]
\caption{Detekcia CNN -- automobil}
\label{tab:cnn1}
\centering
\begin{tabular}{|l r|c|c|c|}
        \hline
        \multicolumn{2}{|c|}{} & \multicolumn{2}{c|}{Na vozovke} & Pri vozovke \\ \hline
        \multicolumn{2}{|c|}{\textbf{Poradie}} & Zastavilo? & Vzdialenosť & Zastavilo? \\ \hline
        & 1 & áno & 12~cm & áno \\ \hline
        & 2 & áno & 13~cm & áno \\ \hline
        & 3 & áno & 12~cm & áno \\ \hline
        & 4 & áno & 11~cm & áno \\ \hline
        & 5 & áno & 12~cm & nie \\ \hline
        \multicolumn{2}{|l|}{\textbf{Úspešnosť}} & 100.00\% & 12~cm & 80.00\% \\ \hline
\end{tabular}
\end{table}
\clearpage
\begin{table}[!ht]
\caption{Detekcia CNN -- nákladné auto}
\label{tab:cnn2}
\centering
\begin{tabular}{|l r|c|c|c|}
        \hline
        \multicolumn{2}{|c|}{} & \multicolumn{2}{c|}{Na vozovke} & Pri vozovke \\ \hline
        \multicolumn{2}{|c|}{\textbf{Poradie}} & Zastavilo? & Vzdialenosť & Zastavilo? \\ \hline
        & 1 & áno & 15~cm & áno \\ \hline
        & 2 & áno & 16~cm & nie \\ \hline
        & 3 & áno & 14~cm & áno \\ \hline
        & 4 & áno & 15~cm & áno \\ \hline
        & 5 & áno & 14~cm & áno \\ \hline
        \multicolumn{2}{|l|}{\textbf{Úspešnosť}} & 100.00\% & 14.8~cm & 80.00\% \\ \hline
\end{tabular}
\end{table}
Tabuľky \ref{tab:cnn1} a \ref{tab:cnn2} zobrazujú úspešnosť detekcie automobilu a nákladného auta. Ak sa objekt nachádza v strede vozovky, úspešnosť detekcie dosahuje 100\%. Priemerná vzdialenosť zastavenia bola v tomto prípade 12~cm pri automobile a 14,8~cm pri nákladnom aute. Úspešnosť však klesla na 80\%, ak sa prekážka nachádzala na okraji vozovky.\par
Tieto prekážky sú rozmerovo veľké, v dôsledku čoho často zaberajú celý záber kamery, prípadne sú len čiastočne viditeľné, ak sa nachádzajú na okraji vozovky. Detekcia je pomerne jednoduchá v situáciách, kedy sú objekty umiestnené v strede jazdného pruhu, pretože ich kľúčové črty sú dobre rozpoznateľné aj z väčšej vzdialenosti. Problém nastáva, ak sú prekážky viditeľné iba sčasti, čo spôsobuje pokles hodnoty istoty (confidence) \acrshort{cnn}.\par
\begin{table}[!ht]
\caption{Detekcia CNN -- bicykel}
\label{tab:cnn3}
\centering
\begin{tabular}{|l r|c|c|c|}
        \hline
        \multicolumn{2}{|c|}{} & \multicolumn{2}{c|}{Na vozovke} & Pri vozovke \\ \hline
        \multicolumn{2}{|c|}{\textbf{Poradie}} & Zastavilo? & Vzdialenosť & Zastavilo? \\ \hline
        & 1 & áno & 10~cm & áno \\ \hline
        & 2 & áno & 13~cm & áno \\ \hline
        & 3 & áno & 11~cm & áno \\ \hline
        & 4 & áno & 13~cm & áno \\ \hline
        & 5 & áno & 12~cm & áno \\ \hline
        \multicolumn{2}{|l|}{\textbf{Úspešnosť}} & 100.00\% & 11.8~cm & 100.00\% \\ \hline
\end{tabular}
\end{table}\clearpage
\begin{table}[!ht]
\caption{Detekcia CNN -- človek}
\label{tab:cnn4}
\centering
\begin{tabular}{|l r|c|c|c|}
        \hline
        \multicolumn{2}{|c|}{} & \multicolumn{2}{c|}{Na vozovke} & Pri vozovke \\ \hline
        \multicolumn{2}{|c|}{\textbf{Poradie}} & Zastavilo? & Vzdialenosť & Zastavilo? \\ \hline
        & 1 & áno & 15~cm & áno \\ \hline
        & 2 & áno & 8~cm & áno \\ \hline
        & 3 & áno & 12~cm & áno \\ \hline
        & 4 & áno & 12~cm & áno \\ \hline
        & 5 & áno & 9~cm & áno \\ \hline
        \multicolumn{2}{|l|}{\textbf{Úspešnosť}} & 100.00\% & 11.2~cm & 100.00\% \\ \hline
\end{tabular}
\end{table}
V tabuľkách \ref{tab:cnn3} a \ref{tab:cnn4} sú zobrazené výsledky testovania s prekážkami typu bicykel a človek. Úspešnosť zastavenia v oboch prípadoch dosiahla 100\%. Priemerná vzdialenosť zastavenia bola 11,8~cm v prípade bicykla a 11,2~cm pri človeku, pričom rozptyl hodnôt bol vyšší ako v predchádzajúcich testoch.\par
Človek a bicykel predstavujú stredne veľké prekážky. Detekčný systém vykazoval o niečo nižšiu stabilitu pri rozpoznávaní týchto objektov v porovnaní s rozmerovo veľkými vozidlami, čo viedlo k väčšej variabilite vzdialenosti, v ktorej došlo k úspešnej detekcii. Na druhej strane, vďaka menším rozmerom týchto prekážok ich bolo možné spoľahlivo detegovať aj v prípade, ak sa nachádzali na okraji vozovky.\par
\begin{table}[!ht]
\caption{Detekcia CNN -- pes}
\label{tab:cnn5}
\centering
\begin{tabular}{|l r|c|c|c|}
        \hline
        \multicolumn{2}{|c|}{} & \multicolumn{2}{c|}{Na vozovke} & Pri vozovke \\ \hline
        \multicolumn{2}{|c|}{\textbf{Poradie}} & Zastavilo? & Vzdialenosť & Zastavilo? \\ \hline
        & 1 & áno & 7~cm & nie \\ \hline
        & 2 & áno & 8~cm & áno \\ \hline
        & 3 & áno & 7~cm & áno \\ \hline
        & 4 & áno & 8~cm & áno \\ \hline
        & 5 & áno & 8~cm & áno \\ \hline
        \multicolumn{2}{|l|}{\textbf{Úspešnosť}} & 100.00\% & 7.6~cm & 80.00\% \\ \hline
\end{tabular}
\end{table}
Tabuľka \ref{tab:cnn5} zobrazuje výsledky detekcie pre triedu pes. Úspešnosť detekcie v strede vozovky dosahuje 100\% s priemernou vzdialenosťou zastavenia 7,6~cm. Pri umiestnení prekážky na okraji vozovky úspešnosť klesla na 80\%. V niektorých prípadoch \acrshort{cnn} chybne klasifikovala prekážku typu pes ako inú triedu (napr. kôň alebo mačka).\par
Trieda pes predstavuje rozmerovo malý typ prekážky. V dôsledku nízkeho rozlíšenia kamery bolo rozpoznávanie tohto objektu náročné, čo sa prejavilo na nízkej priemernej vzdialenosti zastavenia a nesprávnej klasifikácii objektu. Konvolučná sieť bola schopná prekážku detegovať a iniciovať zastavenie až pri jej značnom priblížení. Pri takejto kritickej vzdialenosti by už adekvátne zareagoval aj ultrazvukový senzor. V prípade zlyhania detekcie na okraji vozovky možno predpokladať, že v dôsledku oneskorenej reakcie algoritmu bola táto prekážka systémom úplne ignorovaná.\par
Z nameraných výsledkov je možné vyvodiť koreláciu medzi veľkosťou objektu a úspešnosťou jeho detekcie. Väčšie prekážky (osobné auto, nákladné auto) boli na detekciu jednoduchšie, no pri ich čiastočnom prekrytí alebo orezaní na okraji záberu bola úspešnosť rozpoznania nižšia. Naopak, menšie prekážky (človek, bicykel, pes) umožňujú detekciu v celom zornom poli kamery, avšak vzdialenosť potrebná na ich spoľahlivú detekciu je značne menšia.\par
Pre zvýšenie celkovej bezpečnosti a robustnosti vozidla v reálnych podmienkach sa preto ako nutné javí nasadenie dodatočných kamerových modulov na získanie 360~zorného poľa, implementácia senzorickej fúzie a taktiež rozšírenie trénovacieho datasetu pre umelú inteligenciu o špecifické hraničné scenáre.

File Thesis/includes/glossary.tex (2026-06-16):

\newacronym{av}{AV}{Autonómne vozidlo}
\newacronym{radar}{RADAR}{Radio Detection and Ranging}
\newacronym{lidar}{LiDAR}{Light Detection and Ranging}
\newacronym{gps}{GPS}{Globálny polohovací systém}
\newacronym{ai}{AI}{Umelá inteligencia}
\newacronym{gpio}{GPIO}{General-purpose input/output}
\newacronym{dc}{DC}{Direct Current}
\newacronym{rpm}{RPM}{Revolutions per minute}
\newacronym{api}{API}{Application programming interface}
\newacronym{ide}{IDE}{Integrated Development Enviroment}
\newacronym{ram}{RAM}{Random Access Memory}
\newacronym{cpu}{CPU}{Central Processing Unit}
\newacronym{gpu}{GPU}{Graphics Processing Unit}
\newacronym{cv}{CV}{Computer Vision}
\newacronym{cnn}{CNN}{Convolutional Neural Network}
\newacronym{yolo}{YOLO}{You Only Look Once}
\newacronym{adr}{ADR}{Autonómny doručovací robot}
\newacronym{roi}{ROI}{Region of interest}

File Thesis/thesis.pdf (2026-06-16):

### SLOVENSKÁ TECHNICKÁ UNIVERZITA V BRATISLAVE

### Fakulta elektrotechniky a informatiky

Evidenčné číslo: FEI-16605-126888

# Autonómne riadenie malého vozidla s detekciou prekážky

### Bakalárska práca

### 2026 Rudolf Tisoň

### SLOVENSKÁ TECHNICKÁ UNIVERZITA V BRATISLAVE

### Fakulta elektrotechniky a informatiky

Evidenčné číslo: FEI-16605-126888

## Autonómne riadenie malého vozidla s detekciou prekážky

### Bakalárska práca

Študijný program: | aplikovaná informatika
Študijný odbor: | informatika
Školiace pracovisko: | Ústav informatiky a matematiky
Školiteľ: | Ing. Štefan Bucz, PhD.

2026 Rudolf Tisoň

Študent:
ID študenta:
Študijný program:
Študijný odbor:
Vedúcipráce:
Vedúcipracoviska:

Miesto vypracovania:

Názov práce:

Jazyk, v ktorom sa práca vypracuje:

Špecifikácia zadania:

Slovenská technická univerzita v Bratislave Ústav informatiky a matematiky

slovenský jazyk

Fakulta elektrotechniky a informatiky Akademický rok: 2025/2026
Evidenčné číslo: FEI-16605-126888

# ZADANIE BAKALÁRSKEJ PRÁCE

## Rudolf Tisoň

126888

### aplikovaná informatika informatika

Ing. Štefan Bucz, PhD.
doc. Ing. Milan Vojvoda, PhD.

### Ústav informatiky a matematiky

## Autonómne riadenie malého vozidla s detekciou prekážky

Cieľom bakalárskej práce je návrh a implementácia algoritmu autonómneho riadenia malého vozidla s detekciou prekážky pred vozidlom. Implementácia navrhnutého algoritmu je realizovaná na platforme Arduino s využitím funkcií OpenCV.

Úlohy:
1. Analyzujte súčasný stav riešenia problematiky.
2. Urobte teoretický rozbor autonómneho riadenia.
3. Navrhnite algoritmus autonómneho riadenia vozidla.
4. Realizujte navrhnutý algoritmus.
5. Overte a vyhodnoťte výsledky.

Odporúčaná literatúra:

[1] GRIGORESCU, S.; TRASNEA, B.; COCIAS, T.; MACESANU, G. A survey of deep learning techniques for autonomous driving. Journal of Field Robotics.
Issue. 37. 2019.
[2] PAREKH, D. et al. A Review on Autonomous Vehicles: Progress, Methods and Challenges. 2022. ISSN 2079-9292.

Termín odovzdania bakalárskej práce: Dátum schválenia zadania bakalárskej práce: Zadanie bakalárskej práce schválil:

05. 06. 2026
03. 06. 2026
doc. Mgr. Daniela Chudá, PhD. – garantka študijného programu

## Poďakovanie

Na tomto mieste by som rád poďakoval svojmu vedúcemu práce Ing. Štefanovi Buczovi,

PhD. za cenné rady a čas, ktorý mi venoval. Jeho odborná pomoc a podpora mali významný vplyv na výsledok mojej bakalárskej práce a boli značnou oporou pri jej písaní.

## Abstrakt

Cieľom tejto bakalárskej práce bolo navrhnúť a implementovať malé vozidlo schopné autonómneho riadenia a detekcie prekážok s využitím metód počítačového videnia. Vozidlo bolo vybavené kamerovým modulom ESP32-CAM a ultrazvukovým senzorom, ktoré nepretržite monitorovali priestor pred sebou a poskytovali dáta pre riadiaci server pracujúci v programovacom jazyku Python. Dôležitým prvkom riešenia bolo spracovanie obrazu v knižnici OpenCV, kde sa prostredníctvom rozlíšenia farieb a hľadania kontúr v definovanej oblasti záujmu zabezpečovalo udržiavanie vozidla v stredovej línii vozovky. Na detekciu prekážok bola do systému integrovaná konvolučná neurónová sieť YOLOv8, ktorá spolu s meraním vzdialenosti umožnila vozidlu plynulo reagovať na objekty. Celý hardvérový systém bol riadený platformou Arduino, pričom spracovanie obrazu prebiehalo na serveri, ktorý bezdrôtovo pomocou Wi-Fi komunikoval s vozidlom.

Kľúčové slová

Arduino, OpenCV, Python, detekcia prekážky, autonómne vozidlo

## Abstract

The objective of this bachelor’s thesis was to design and implement a small vehicle capable of autonomous driving and obstacle detection using computer vision methods. The vehicle was equipped with an ESP32-CAM camera module and an ultrasonic sensor, which continuously monitored the area ahead and provided data for a control server operating in the Python programming language. An important element of the solution was image processing in the OpenCV library, where maintaining the vehicle within the center line of the lane was ensured through color thresholding and contour detection in a defined region of interest. For obstacle detection, a YOLOv8 convolutional neural network was integrated into the system, which, together with distance measurement, enabled the vehicle to respond smoothly to objects. The entire hardware system was controlled by the Arduino platform, while image processing took place on the server, which communicated wirelessly with the vehicle via Wi-Fi.

Keywords

Arduino, OpenCV, Python, obstacle detection, autonomous vehicle

## Obsah

Úvod | 11
1 Autonómne vozidlá | 12
2 Ciele práce | 14
3 Analýza súčasného stavu | 15
4 Komponenty systému | 20
5 Softvér | 25

6 Návrh a implementácia | 28
7 Metodika testovania | 47
8 Výsledky | 51
Záver | 57
Literatúra | 59
A Výpis dlhého kódu | I
B Výsledky testov | II

## Zoznam obrázkov a tabuliek

Obrázok 1 | Ako AV vnímaju prostredie | | 16
Obrázok 2 | Arduino Nano ESP32 | | 20
Obrázok 3 | ESP32-CAM a OV2640 | | 21
Obrázok 4 | HC-SR04 ultrazvukový modul | | 22
Obrázok 5 | DRV8833 driver pre motorčeky | | 23
Obrázok 6 | Typická CNN | | 27
Obrázok 7 | Obraz s použitím ROI | | 29
Obrázok 8 | Hľadanie tmavého jazdného pruhu | | 31
Obrázok 9 | Diagram fungovania ultrazvukového senzora | | 32
Obrázok 10 | Detekcia prekážky pomocou CNN | | 35
Obrázok 11 | Hľadanie stredu jazdného pruhu | | 37
Obrázok 12 | Sekvenčný diagram vyhodnotenia dát zo senzorov | | 38
Obrázok 13 | Diagram komunikácie komponentov | | 39
Obrázok 14 | 3D model vozidla | | 43
Obrázok 15 | Integrované vývojové prostredie Arduino | | 44
Obrázok 16 | Delič napätia | | 45
Obrázok 17 | Skompletizované vozidlo (predok) | | 46
Obrázok 18 | Skompletizované vozidlo (zadok) | | 46
Obrázok 19 | Testovacia trať | | 48
Obrázok 20 | Prekážky na testovanie ultrazvukového modulu | | 49
Obrázok 21 | Prekážky na testovanie CNN | | 50
Tabuľka 1 | Detekcia jazdného pruhu | | 51
Tabuľka 2 | Ultrazvukový senzor (stred vozovky) | | 52
Tabuľka 3 | Ultrazvukový senzor (mimo vozovky) | | 52
Tabuľka 4 | Ultrazvukový senzor (pri vozovke) | | 53
Tabuľka 5 | Detekcia CNN – automobil | | 53
Tabuľka 6 | Detekcia CNN – nákladné auto | | 54
Tabuľka 7 | Detekcia CNN – bicykel | | 54
Tabuľka 8 | Detekcia CNN – človek | | 55
Tabuľka 9 | Detekcia CNN – pes | | 55

## Zoznam značiek a skratiek

ADR | Autonómny doručovací robot
AI | Umelá inteligencia
API | Application programming interface
AV | Autonómne vozidlo
CNN | Convolutional Neural Network
CPU | Central Processing Unit
DC | Direct Current
GPIO | General-purpose input/output
GPS | Globálny polohovací systém
GPU | Graphics Processing Unit
IDE | Integrated Development Enviroment
LiDAR | Light Detection and Ranging
RADAR Radio Detection and Ranging
RAM | Random Access Memory
ROI | Region of interest
RPM | Revolutions per minute
YOLO | You Only Look Once

## Zoznam výpisov kódov

1 | Funkcia ROI | | 28
2 | Definície maxima a minima tmavých regiónov | | 29
3 | Maskovanie tmavých regiónov | | 30
4 | Detekcia kontúr | | 32
5 | Obsluha prerušenia ultrazvukového senzora | | 33
6 | Výpočet vzdialenosti z merania ultrazvukového senzora | | 33
7 | Príprava CNN na detekciu objektov | | 34
8 | Rozhodovanie zastavenia pri detekcii pomocou CNN | | 35
9 | Výpočet geometrického stredu kontúry | | 36
10 | Výpočet hodnoty riadenia | | 37
11 | Rozhodovanie na vozidle | | 37
12 | Zapnutie Wi-Fi hotspotu | | 40
13 | Pingovanie IP adresy kamerového modulu | | 40
14 | Spustenie HTTP stream na ESP32-CAM | | 41
15 | Posielanie UDP packetov | | 41
16 | Vnútorný cyklus Arduina | | 42

## Úvod

Autonómne vozidlá sú v súčasnosti jedným z najrýchlejšie sa rozvíjajúcich technologických odvetví. Ide o formu mobility, ktorá je bezpečnejšia, efektívnejšia a pohodlnejšia než konvenčné spôsoby dopravy riadené človekom. Zavedenie autonómnych vozidiel vedie k presunu pracovnej sily od rutinných manuálnych úkonov smerom k činnostiam zameraným na monitorovanie, manažovanie a kontrolu systémov. Taktiež umožňujú ľuďom s fyzickým postihnutím samostatne operovať automobil. V súčasnosti sú vozidlá s čiastočnou autonómiou dostupné pre každého, kto túži po luxuse, ktorý tieto autá poskytujú, a má na to potrebné financie.

Autonómne vozidlá sa rozdeľujú do šiestich stupňov autonómie, od 0 (žiadna autonómia) až po 5 (úplná autonómia bez nutnosti zásahu človeka). Na nahradenie funkcií

človeka využívajú senzory na vnímanie okolia a umelú inteligenciu na rozhodovanie. Technologické spoločnosti sa v tejto oblasti snažia o čo najefektívnejšie prepojenie týchto dvoch systémov.

Najväčšími bariérami pri integrácii autonómnych vozidiel do bežnej spoločnosti sú ich vysoká cena a neschopnosť navigovať v komplikovaných hraničných situáciách. Súčasný vývoj sa snaží tieto bariéry aktívne prekonávať.

Cieľom bakalárskej práce je navrhnúť a implementovať riešenie autonómneho vozidla, ktoré je schopné detekovať prekážky a adekvátne na ne reagovať. Projekt realizujeme na platforme Arduino s využitím knižnice na počítačové videnie OpenCV. V rámci práce preskúmame aktuálne prístupy k autonómii a zvážime životaschopnosť súčasných trendov. Výstupom bude praktická implementácia modelu vozidla a jeho testovanie v rôznych situáciách.

Výber témy bakalárskej práce vychádza z nášho záujmu o automatizáciu a inovácie v oblasti automobilov. Daná téma spája mnohé populárne technológie, ako je umelá inteligencia a automatizácia logistiky. Zároveň nás zaujala práca s mikrokontrolérmi a elektronikou. Práve kombináciou týchto oblastí sme sa pre túto tému nadchli.

## 1 Autonómne vozidlá

## 1.1 Čo je to autonómne vozidlo?

Autonómne vozidlo (AV), niekedy nazývané aj samoriadiace auto je dopravný prostrie-

dok, ktorý, na rozdiel od tradičných vozidiel nevyžaduje vodiča. Autonómne vozidlá vykonávajú túto úlohu pomocou viacerých hardvérových a softvérových systémov. Hoci ani v roku 2026 nemá termín ’samoriadiace’ jednotnú štadardnú definíciu, hlavným cieľom týchto technológií zostáva eliminácia ľudských chýb, zvýšenie efektivity premávky a sprístupnenie prepravy ľudom, ktorí nie sú schopní šoférovať sami [1].

Na vnímanie okolia vozidla používame senzory detekcie objektov. Systém vnímania používa kamery, Radio Detection and Ranging (RADAR), Light Detection and Ranging (LiDAR) a ultrazvukové senzory, pričom každý z nich má špecifickú funkciu. Autonómne

vozidlá často pracujú s čiastočne neznámym a dynamickým prostredím, preto si musia vystavať model svojho prostredia a zároveň sa v ňom lokalizovať. Tento proces je známy pod skratkou SLAM (súčasná lokalizácia a mapovanie) [1].

Spočíva v spracovaní dát zo senzorov, máp a systéme globálneho polohovacieho systému (GPS), vďaka čomu si zariadenie vytvorí model prostredia a určí v ňom svoju polohu v reálnom čase [1].

Tretí systém je zodpovedný za plánovanie a rozhodovanie. Na základe dát z predchádzajúcej vrstvy vozidlo vyhodnocuje a reaguje na vývoj dopravnej situácii. Táto vrstva má mnoho funkcií od plánovania trasy po vyhýbanie sa prekážkam. Najčastejšie sa používajú modely strojového učenia, vrátane neurónových sietí [1].

Posledným článkom je konanie a ovládanie. Systém ovládania vozidla premení abstraktné požiadavky predchádzajúcej vrstvy na fyzické pohyby auta. Zodpovedá za smerové riadenie, zrýchľovanie a brzdenie.

Pokročilé algoritmy zároveň zabezpečujú, aby pohyb bol plynulý, stabilný a rešpektoval limitácie podvozku. Vďaka integrácii týchto systémov dokáže autonómne vozidlo navigovať v komplexných dopravných situáciách s minimálnou až nulovou potrebou ľudského zásahu [1].

## 1.2 Úrovne autonómnych vozidiel

Úrovne autonómnych vozidiel sú definované organizáciou SAE International v štandarde

SAEJ3016. Tento dokument delí automatizáciu riadenia do šiestich stupňov (0–5) podľa

toho, akú časť jazdy zabezpečuje systém a akú úlohu ešte stále zohráva vodič. O samoriadiacich autách sa často hovorí, ako o jednej kategórii, no v praxi ide o postupný vývoj od minimálnej podpory riadenia až po úplnú autonómiu vozidla bez zásahu človeka [2].

### 1.2.1 Úroveň 0

Žiadna automatizácia Na tejto úrovni všetky činnosti vykonáva ľudský vodič.

Vozidlo môže mať bezpečnostné systémy, ako napríklad upozornenie opustenia jazdného pruhu, no samotné riadenie je plne v rukách človeka [2].

### 1.2.2 Úroveň 1

Asistované riadenie Systém pomáha s postranným alebo pozdĺžnym riadením

vozidla ale nie v obidvoch prípadoch naraz. Sem patria asistencie, ako udržiavanie rýchlosti (tempomat) alebo mierne korigovanie smeru. Vodič však musí neustále sledovať situáciu na vozovke a mať ruky na volante [2].

### 1.2.3 Úroveň 2

Čiastočná automatizácia Vozidlo dokáže súčasne riadiť smer aj rýchlosť, stále však

platí, že vodič nepretržite dohliada na jazdu a je pripravený zasiahnuť v prípade núdze. Systém vykonáva viac úloh riadenia naraz, no zodpovednosť upadá na človeka [2].

### 1.2.4 Úroveň 3

Podmienená automatizácia Jazda v špecifickej situácii je automatizovaná a vodič nemusí aktívne sledovať okolie. Ak však systém vyhodnotí, že situáciu nezvládne, kontrola vozidla sa vráti vodičovi. Vodič musí byť pripravený prevziať kontrolu nad vozidlom [2].

### 1.2.5 Úroveň 4

Vysoká automatizácia Na tejto úrovni je vozidlo schopné zvládnuť jazdu úplne samo v rámci definovaných prostredí alebo podmienok. V prípade, že sa vozidlo dostane mimo týchto podmienok, dokáže bezpečne zastaviť. Prítomnosť ľudského šoféra nie je nutná [2].

### 1.2.6 Úroveň 5

Plná automatizácia Najvyšší stupeň automatizácie, vozidlo dokáže jazdiť samostatne za všetkých podmienok, v ktorých dokáže jazdiť človek. Neexistuje potreba vodiča. Vozidlo zastaví v prípade zlyhania určitých modulov riadenia [2].

## 2 Ciele práce

V tejto kapitole si stanovíme hlavný cieľ bakalárskej práce a taktiež čiastkové ciele, ktoré slúžia, ako miľníky pri praktickom spracovaní témy práce.

Hlavný cieľ bakalárskej práce je návrh a implementácia algoritmu pre autonómne riadenie malého robotického vozidla, ktoré dokáže v reálnom čase detegovať prekážky v jazdnej dráhe a následne na ne reagovať.

Praktická časť práce sa zameriava na implementáciu riešenia na hardvérovej platforme Arduino so súčasnými metódami počítačového videnia pomocou knižnice OpenCV.

## 2.1 Čiastkové ciele

1. Analýza problematiky: Teoretické spracovanie aktuálnej problematiky v oblasti autonómnych vozidiel. Zhodnotenie súčasnej a budúcej implementácie jednotlivých systémov použitých v AV. Prehľad konkrétneho využitia senzorových systémov a umelej inteligencie na detekciu prekážok.
2. Návrh technologického riešenia: Výber optimálnej kombinácie hardvérových a softvérových komponentov v rámci obmedzenia bakalárskej práce. Zvolenie riadiacej jednotky Arduino, typ a počet senzorov, programovací jazyk riešenia a mechanické prvky vozidla. Výber metód detekcie prekážky a jazdného pruhu pomocou počítačového videnia. Fyzický návrh vzhľadu vozidla so zameraním na použité materiály a rozloženie komponentov.
3. Algoritmizácia detekcie: Zvolenie riešení v prostredí OpenCV zameraných na spracovanie obrazu z kamery na identifikáciu prekážok a jazdného pruhu v zornom poli vozidla.
4. Prepojenie komponentov: Návrh metód komunikácie jednotlivých komponentov. Prepojenie vrstiev riadenia autonómneho vozidla od vnímania po konanie. Interpretácia výstupov na vstupy pre jednotlivé systémy. Návrh fyzického prepojenie častí systému pomocou komunikačného média.
5. Zostavenie riešenia: Implementácia zvolených návrhov. Naprogramovanie riešenia s použitím knižnice OpenCV. Zostavenie rámu vozidla a následná montáž.
6. Testovanie a validácia: Navrhnutie metodiky testovania a následné overenie funkčnosti vozidla v rozličných situáciách. Otestovanie detekcie rôznych prekážok.

## 3 Analýza súčasného stavu

## 3.1 Aktuálny stav technológie

V posledných rokoch sme zaznamenali nárast vozidiel s treťou úrovňou autonómie, autonómne taxi služby sa v mestách stávajú reálnym spôsobom dopravy a videli sme už aj prvé ukážky kamiónov bez nutnosti ľudského vodiča [3][4].

Vďaka vývoju v oblasti umelej inteligencie a zvýšenia výkonu výpočtových platforiem sme zaregistrovali značný pokrok v technológiách autonómnych vozidiel. Výrobcovia sa snažia zlepšovať kombinácie radarových, LiDARových a kamerových dát tak, aby boli robustnejšie voči dopravným a poveternostným podmienkam. Pokračuje snaha v návrhu scenárov pre hraničné situácie, čím sa zlepší percepčná schopnosť autonómnych systémov a zrýchli ich nasadenie [5][6].

Autonómne vozidla zaznamenali značnú investíciu ale aj kontrolu zo strany štátnych a nadnárodných organizácií. Spoločnosti, ktoré poskytujú služby samoriadiacich vozidiel rozširujú svoju dostupnosť, znižujú počet senzorov a náklady na hardvér. Hoci technologický pokrok napreduje, integrácia do infraštruktúry mesta zostáva podstatnou výzvou pre adopciu AV do dopravy. Štandard SAE International preto opisuje plán

prechodu od asistencie šoférovania po plne autonómnu prevádzku [7][8].

### 3.1.1 Umelá inteligencia

Umelá inteligencia (AI) vykonáva dôležitú funkciu v percepčnom, rozhodovacom a

plánovacom systéme autonómneho vozidla, čím nahrádza rolu ľudského vodiča. Moderné systémy používajú strojové učenie (machine learning) na detekciu hazardov na ceste,

klasifikáciu dopravných značiek a sledovanie a predikciu pohybu chodcov a ostatných vozidiel [9].

V súčasnosti sa autonómne modely trénujú na obrovskom množstve anotovaných obrázkov, videí, simulácií a skutočných jazdných dát, aby v praxi zvládli širokú škálu scenárov. Hlboké učenie (deep learning) a učenie posilňovaním (reinforcement learning)

sa používajú v novodobých autonómnych vozidlách. Deep learning, podskupina strojového učenia, pracuje na princípe viacvrstvových neurónových sietí, čím sa fungovaním podobá ľudskému mozgu. Reinforcement learning mení správanie modelu využitím systému odmien a penalizácií [10].

Napriek značnej komplexnosti zostáva riešenie hraničných prípadov (edge cases)

zásadnou výzvou pre dnešné systémy. Potreba veľkého množstva tréningových dát a vysoká hranica bezpečnosti a spoľahlivosti výrazne spomaľuje nasadenie vozidiel do reálnej premávky [6].

### 3.1.2 Senzory

Senzory sú spôsob akým autonómne vozidlá vnímajú svoje okolie. Ako je možné vidieť na obrázku 1, v súčasnosti sa v autách využíva kombinácia kamier, LiDARových, radarových a ultrazvukových senzorov [11].


Obr. 1: Ako AV vnímaju prostredie

[9], licencia: CC BY-SA 4.0. (https://creativecommons.org/licenses/by-sa/4.0/deed.en)

Kamery predstavujú najrozšírenejší typ senzorov; sú nákladovo efektívne, no citlivé na zlé osvetlenie a počasie. Používajú sa na detekciu jazdných pruhov, rozpoznávanie dopravných značiek a identifikáciu chodcov a vozidiel. RADAR využíva elektromagnetické vlny na meranie vzdialenosti a rýchlosti. Používa sa najmä pre detekciu vzdialených objektov aj v nepriaznivých poveternostných podmienkach (dážď, hmla, sneh). LiDAR

používa laserové impulzy na vytvorenie detailného trojrozmerného modelu okolia, no okrem vysokých nákladov je aj viac náchylný na zlé počasie. Ultrazvukové senzory majú využitie v detekcii objektov na krátke vzdialenosti, napríklad pri parkovacích manévroch. Na rozdiel od fotoelektrických senzorov (napr. RADAR), nie sú ovplyvnené farbou alebo odrazivosťou cieľa, pretože používajú zvuk a nie svetlo [1][11].

Súčasný vývoj v oblasti senzorov sa zameriava primárne na zvyšovanie presnosti meranie, optimalizovanie počtu potrebných senzorov a výrazné znižovanie ich ceny. Výrobcovia taktiež zefektívňujú kombinovanie dát viacerých senzorov, tzv. senzorovú fúziu, čím zvyšujú presnosť a spoľahlivosť systému [8][9].

## 3.2 Použitie autonómnych vozidiel

Autonómne vozidlá ponúkajú široké spektrum využitia, pričom ich možnosti sa v posledných rokoch rozširujú. K najpozoruhodnejším oblastiam ich využitia patrí doprava. Hlavným cieľom je zvýšiť bezpečnosť a plynulosť premávky. Ďalšie využitie je v logistike

tovaru, kde nahrádzajú rutinnú manuálnu prácu tradične vykonávanú ľudmi.

### 3.2.1 Autonómne taxi služby

Autonómne taxi služby, často nazývané robotaxíky, predstavujú jednu z najpokročilejších foriem využitia autonómnych technológií. Celý proces – od objednania a naplánovania trasy až po samotnú prepravu pasažierov – je plne automatizovaný.

Mnohí výrobcovia automobilov, technologické spoločnosti a štátne organizácie investujú zdroje do vývoja robotaxíkov. Na popredí stojí spoločnosť Waymo, dcérska spoločnosť amerického konglomerátu Alphabet. Ich vozidlá, spĺňajúce štvrtú úroveň

autonómie, využívajú LiDAR, RADAR a kamery na vytváranie trojrozmerného obrazu okolia. S každou ďalšou generáciou vozidiel navyše redukujú počet senzorov, čím znižujú výrobné náklady a zlepšujú škálovateľnosť celého projektu [8].

Alternatívny prístup zvolila spoločnosť Tesla so svojou službou Robotaxi a systémom FSD (Full Self-Driving), ktorý predstavuje tretí stupeň autonómneho riadenia. Na rozdiel

od konkurencie nepoužíva finančne nákladné LiDAR senzory, ale spolieha sa výhradne na kamerový systém s interpretáciou dát pomocou umelej inteligencie. Hoci pri bežných vozidlách nad jazdou stále dohliada ľudský operátor pripravený kedykoľvek prevziať kontrolu, v roku 2026 začala spoločnosť do svojej flotily zavádzať prvé vozidlá v plne autonómnom režime bez ľudského dozoru [12].
Ďalším významným hráčom je spoločnosť Nvidia s modelom Alpamayo 1. Tento open-

-source model uvažovania je navrhnutý a trénovaný špeciálne na zvládanie komplexných a kritických dopravných situácií. Vydanie tohto voľne dostupného riešenia má za cieľ výrazne urýchliť integráciu štvrtej a piatej úrovne AV do bežnej premávky [6].
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

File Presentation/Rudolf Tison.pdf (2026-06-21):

# Autonómne riadenie malého vozidla s detekciou prekážky

### Rudolf Tisoň

Ing. Štefan Bucz, PhD.

## Autonómne vozidlá a ich rozvoj

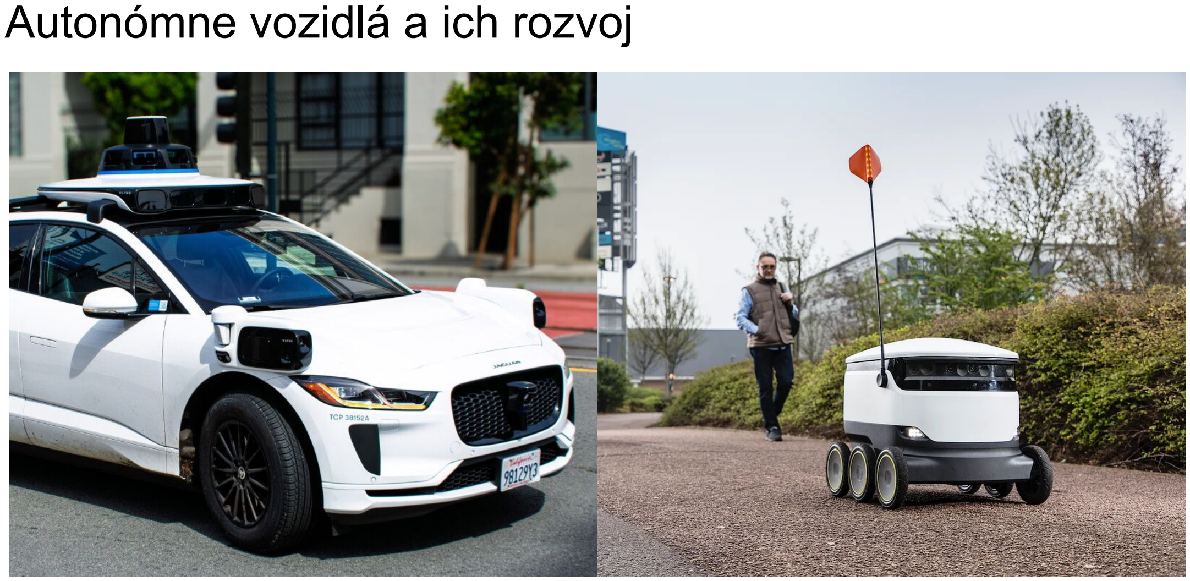
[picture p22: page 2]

## Ciele a obmedzenia práce

1. Analýza aktuálnych trendov v oblasti autonómnych vozidiel.
2. Rozbor teórie autonómneho riadenia.
3. Návrh algoritmu autonómneho vozidla.
4. Realizácia (softvérová a hardvérová).
5. Testovanie a vyhodnotenie výsledkov.

Explicitné obmedzenia:

- Platforma Arduino.
- Spracovanie obrazu pomocou OpenCV.

Implicitné obmedzenia:

- Nízky výpočtový výkon
mikrokontrolérov Arduino.
- Nízke rozlíšenie kamery.

## Návrh algoritmu detekcie čiar v OpenCV

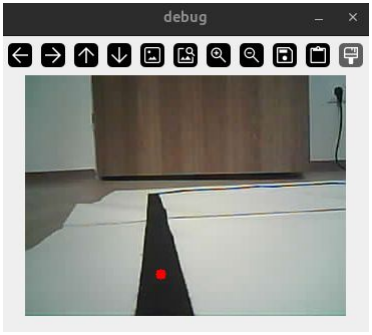
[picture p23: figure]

### 1. Region of interest

→ Vystrihnúť spodok obrazu na analýzu.

### 2. Farebný thresholding

→ Detekcia tmavých regiónov, → Vyčistenie obrazu (diery a ostrovčeky).

### 3. Hľadanie kontúr

→ Vyhľadanie a následné
zjednodušenie čiar.

### 4. Interpretácia na hodnotu riadenia

## Návrh detekcie prekážky pomocou ultrazvukového senzora

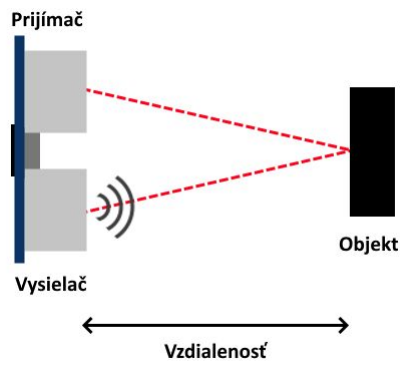
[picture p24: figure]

### 1. Vyslanie ultrazvukového pulzu

→ Každých 50 ms zavolané
prerušenie.

### 2. Spustenie časovača

### 3. Počúvanie návratového pulzu

### 4. Výpočet vzdialenosti

→ Pomocou rýchlosti vzduchu a času z časovača.

### 5. Rozhodnutie zastavenia

## Návrh detekcie prekážky pomocou CNN

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

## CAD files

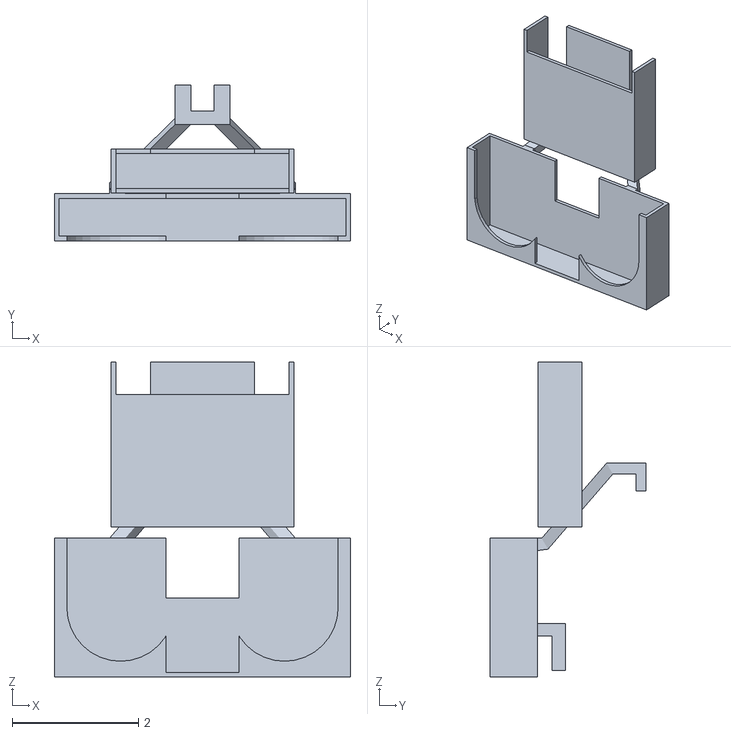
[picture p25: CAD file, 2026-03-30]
Model/holder.stl
4.70 x 2.47 x 4.99

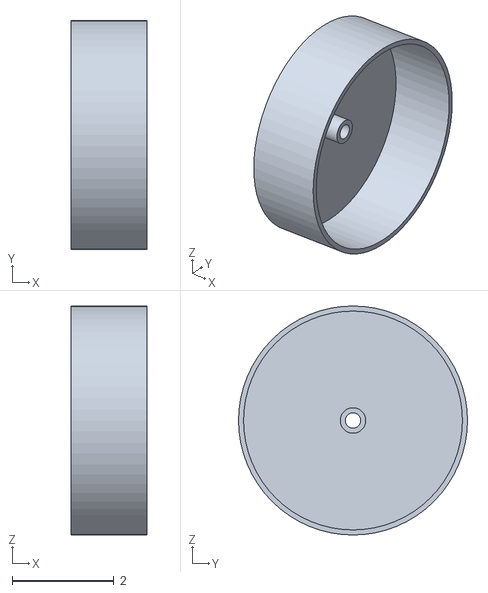
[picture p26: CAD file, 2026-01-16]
Model/wheel.stl
1.50 x 4.50 x 4.50

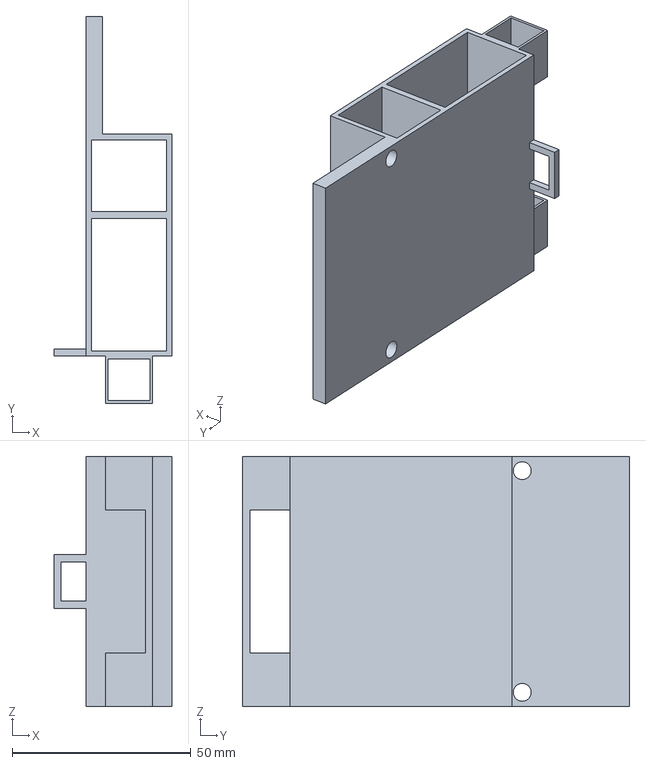
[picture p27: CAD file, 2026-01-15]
Model/chassis.3mf
33.0 x 108.3 x 70.0 mm

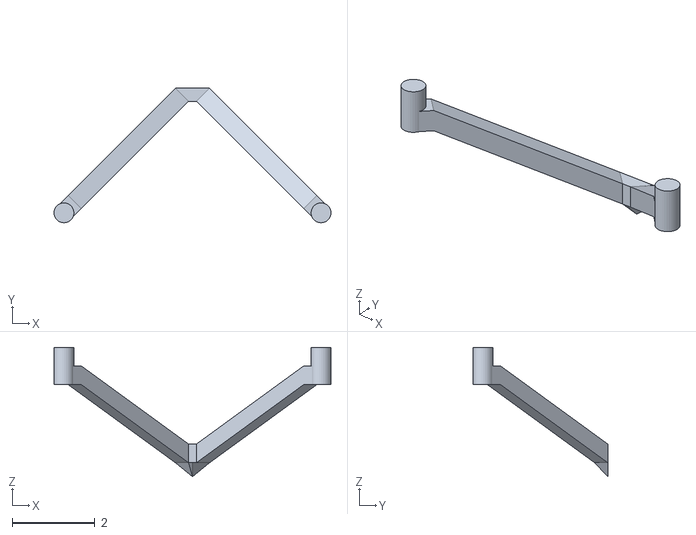
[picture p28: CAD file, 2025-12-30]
Model/fork.stl
6.68 x 3.25 x 3.12

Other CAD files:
Model/chassis.blend
Model/chassis.stl

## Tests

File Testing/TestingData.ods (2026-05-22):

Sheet: TrackDetection
Poradie | Čas | Nedokončilo?
1 | 11.88 s | nie
2 | 12.35 s | nie
3 | n/a | áno
4 | 13.13 s | nie
5 | 13.80 s | nie
6 | 12.48 s | nie
7 | 14.84 s | nie
8 | 12.89 s | nie
9 | 11.92 s | nie
10 | 11.38 s | nie
Priemer | 12.74 s | 90.00%

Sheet: UltraSound
Pri ceste
Poradie | Zastavilo?
 | Štíhla | Stredná | Široká
1 | nie | nie | nie
2 | nie | nie | nie
3 | nie | nie | nie
4 | nie | nie | nie
5 | nie | nie | nie
Úspešnosť | 0.00% | 0.00% | 0.00%
Na ceste
Poradie | Zastavilo?
 | Štíhla | Stredná | Široká
1 | áno | áno | áno
2 | áno | áno | áno
3 | áno | áno | áno
4 | áno | áno | áno
5 | áno | áno | áno
Úspešnosť | 100.00% | 100.00% | 100.00%
Mimo cesty
Poradie | Zastavilo?
 | Štíhla | Stredná | Široká
1 | nie | nie | nie
2 | nie | nie | nie
3 | nie | nie | nie
4 | nie | nie | nie
5 | nie | nie | nie
Úspešnosť | 100.00% | 100.00% | 100.00%

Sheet: CNN
Automobil |  |  |  | Nákladné auto
Poradie | Zastavilo? | Vzdialenosť | Zastavilo? | Poradie | Zastavilo? | Vzdialenosť | Zastavilo?
1 | áno | 12 cm | áno | 1 | áno | 15 cm | áno
2 | áno | 13 cm | áno | 2 | áno | 16 cm | nie
3 | áno | 12 cm | áno | 3 | áno | 14 cm | áno
4 | áno | 11 cm | áno | 4 | áno | 15 cm | áno
5 | áno | 12 cm | nie | 5 | áno | 14 cm | áno
Úspešnosť | 100.00% | 12 cm | 80.00% | Úspešnosť | 100.00% | 14.8 cm | 80.00%
Bicykel |  |  |  | Človek
Poradie | Zastavilo? | Vzdialenosť | Zastavilo? | Poradie | Zastavilo? | Vzdialenosť | Zastavilo?
1 | áno | 10 cm | áno | 1 | áno | 15 cm | áno
2 | áno | 13 cm | áno | 2 | áno | 8 cm | áno
3 | áno | 11 cm | áno | 3 | áno | 12 cm | áno
4 | áno | 13 cm | áno | 4 | áno | 12 cm | áno
5 | áno | 12 cm | áno | 5 | áno | 9 cm | áno
Úspešnosť | 100.00% | 11.8 cm | 100.00% | Úspešnosť | 100.00% | 11.2 cm | 100.00%
Pes
Poradie | Zastavilo? | Vzdialenosť | Zastavilo?
1 | áno | 7 cm | nie
2 | áno | 8 cm | áno
3 | áno | 7 cm | áno
4 | áno | 8 cm | áno
5 | áno | 8 cm | áno
Úspešnosť | 100.00% | 7.6 cm | 80.00%

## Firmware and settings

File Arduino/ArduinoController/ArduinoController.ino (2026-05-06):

#include <WiFi.h>
#include <WiFiUdp.h>

// WiFi Settings + UDP Buffer
const char* ssid = "LAPTOP_AP";
const char* password = "12345678";

WiFiUDP udp;
unsigned int localPort = 5005;
uint8_t incoming[2];
int steer = -256;

// Ultrasound sensor pins
#define TRIG_PIN D2
#define ECHO_PIN D3

// Ultrasound variables
volatile uint32_t echoStart = 0;
volatile uint32_t echoEnd = 0;
volatile bool echoDone = false;
uint16_t distance = 0;

// Driver OUT pins
#define L_PINA D7
#define L_PINB D5
#define R_PINA D9
#define R_PINB D11

// Driver constants
const int BASE_SPEED = 200;
const int PWM_FREQ = 20000;
const int PWM_RES = 8;

// Print-outs
void printDistance(int distance) {
  Serial.print("Distance: ");
  Serial.print(distance);
  Serial.print("cm\n");
}

void printPacket(int steer) {
  Serial.print("Packet: ");
  Serial.print(steer);
  Serial.print("\n");
}

// Motor Functions
void setMotor(int pinA, int pinB, int speed) {
  if (speed > 0) {
    ledcWrite(pinA, speed);
    ledcWrite(pinB, 0);
  } else {
    ledcWrite(pinA, 0);
    ledcWrite(pinB, -speed);
  }
}

void driveSteering(int steer) {
  if (steer > -16 && steer < 16) steer = 0;

  int left = constrain(BASE_SPEED + steer, -255, 255);
  int right = constrain(BASE_SPEED - steer, -255, 255);

  setMotor(0, 1, left);
  setMotor(2, 3, right);
}

void stopWheels() {
  ledcWrite(0, 0);
  ledcWrite(1, 0);
  ledcWrite(2, 0);
  ledcWrite(3, 0);
}

// Ultrasound control functions
void IRAM_ATTR echoISR() {
  if (digitalRead(ECHO_PIN)) {
    echoStart = micros();
  } else {
    echoEnd = micros();
    echoDone = true;
  }
}

void triggerUltrasonic() {
  digitalWrite(TRIG_PIN, LOW);
  delayMicroseconds(2);
  digitalWrite(TRIG_PIN, HIGH);
  delayMicroseconds(10);
  digitalWrite(TRIG_PIN, LOW);
}

void setup() {
  Serial.begin(115200);
  
  // Ultrasound setup
  pinMode(TRIG_PIN, OUTPUT);
  pinMode(ECHO_PIN, INPUT);
  attachInterrupt(ECHO_PIN, echoISR, CHANGE);

  // Setup PWM pins
  ledcSetup(0, PWM_FREQ, PWM_RES);
  ledcSetup(1, PWM_FREQ, PWM_RES);
  ledcSetup(2, PWM_FREQ, PWM_RES);
  ledcSetup(3, PWM_FREQ, PWM_RES);

  // Attach PWM pins to channels
  ledcAttachPin(L_PINA, 0);
  ledcAttachPin(L_PINB, 1);
  ledcAttachPin(R_PINA, 2);
  ledcAttachPin(R_PINB, 3);

  WiFi.begin(ssid, password);
  while (WiFi.status() != WL_CONNECTED) {
    delay(200);
  }

  udp.begin(localPort);
}

void loop() {
  while (udp.parsePacket() >= 2) {
    udp.read(incoming, 2);

    uint16_t raw = incoming[0] | (incoming[1] << 8);
    steer = (int)raw - 256;
  }

  static unsigned long lastTrig = 0;
  if (millis() - lastTrig > 50) {
    lastTrig = millis();
    echoDone = false;
    triggerUltrasonic();
  }

  if (echoDone) {
    uint32_t duration = echoEnd - echoStart;
    distance = duration / 58;
    echoDone = false;
  }

  if (distance < 10 || steer < -255 || steer > 255) {
    stopWheels();
  } else {
    driveSteering(steer);
  }
}

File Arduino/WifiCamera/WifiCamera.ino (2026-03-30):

#include "esp_camera.h"
#include <WiFi.h>
#include "esp_timer.h"
#include "Arduino.h"
#include "esp_http_server.h"

// ---------------- Wi-Fi ----------------
const char* ssid = "LAPTOP_AP";
const char* password = "12345678";

// ---------------- Kamera ----------------
// Piny pre ESP32-CAM (AI-Thinker)
#define PWDN_GPIO_NUM     32
#define RESET_GPIO_NUM    -1
#define XCLK_GPIO_NUM      0
#define SIOD_GPIO_NUM     26
#define SIOC_GPIO_NUM     27
#define Y9_GPIO_NUM       35
#define Y8_GPIO_NUM       34
#define Y7_GPIO_NUM       39
#define Y6_GPIO_NUM       36
#define Y5_GPIO_NUM       21
#define Y4_GPIO_NUM       19
#define Y3_GPIO_NUM       18
#define Y2_GPIO_NUM        5
#define VSYNC_GPIO_NUM    25
#define HREF_GPIO_NUM     23
#define PCLK_GPIO_NUM     22

// ---------------- Funkcie ----------------
httpd_handle_t stream_httpd = NULL;

// Stream handler
esp_err_t stream_handler(httpd_req_t *req){
  camera_fb_t * fb = NULL;
  char * part_buf[64];
  static const char* _STREAM_CONTENT_TYPE = "multipart/x-mixed-replace;boundary=frame";

  httpd_resp_set_type(req, _STREAM_CONTENT_TYPE);

  while(true){
    fb = esp_camera_fb_get();
    if(!fb){
      httpd_resp_send_500(req);
      return ESP_FAIL;
    }

    // HTTP multipart
    httpd_resp_send_chunk(req, "--frame\r\n", 9);
    sprintf((char*)part_buf, "Content-Type: image/jpeg\r\nContent-Length: %u\r\n\r\n", fb->len);
    httpd_resp_send_chunk(req, (const char*)part_buf, strlen((char*)part_buf));
    httpd_resp_send_chunk(req, (const char*)fb->buf, fb->len);
    httpd_resp_send_chunk(req, "\r\n", 2);

    esp_camera_fb_return(fb);
    delay(30); // ~30 FPS
  }

  return ESP_OK;
}

// Spustenie HTTP stream servera
void startCameraServer(){
  httpd_config_t config = HTTPD_DEFAULT_CONFIG();
  config.server_port = 81; // port streamu

  if(httpd_start(&stream_httpd, &config) == ESP_OK){
    httpd_uri_t stream_uri = {
      .uri       = "/stream",
      .method    = HTTP_GET,
      .handler   = stream_handler,
      .user_ctx  = NULL
    };
    httpd_register_uri_handler(stream_httpd, &stream_uri);
  }
}

// ---------------- Setup ----------------
void setup() {
  Serial.begin(115200);

  // Wi-Fi
  while(WiFi.status() != WL_CONNECTED){
    delay(500);
  }

  // Kamera
  camera_config_t config;
  config.ledc_channel = LEDC_CHANNEL_0;
  config.ledc_timer   = LEDC_TIMER_0;
  config.pin_d0 = Y2_GPIO_NUM;
  config.pin_d1 = Y3_GPIO_NUM;
  config.pin_d2 = Y4_GPIO_NUM;
  config.pin_d3 = Y5_GPIO_NUM;
  config.pin_d4 = Y6_GPIO_NUM;
  config.pin_d5 = Y7_GPIO_NUM;
  config.pin_d6 = Y8_GPIO_NUM;
  config.pin_d7 = Y9_GPIO_NUM;
  config.pin_xclk = XCLK_GPIO_NUM;
  config.pin_pclk = PCLK_GPIO_NUM;
  config.pin_vsync = VSYNC_GPIO_NUM;
  config.pin_href = HREF_GPIO_NUM;
  config.pin_sscb_sda = SIOD_GPIO_NUM;
  config.pin_sscb_scl = SIOC_GPIO_NUM;
  config.pin_pwdn = PWDN_GPIO_NUM;
  config.pin_reset = RESET_GPIO_NUM;
  config.xclk_freq_hz = 20000000;
  config.pixel_format = PIXFORMAT_JPEG;

  if(psramFound()){
    config.frame_size = FRAMESIZE_QVGA;
    config.jpeg_quality = 12;
    config.fb_count = 2;
  } else {
    config.frame_size = FRAMESIZE_QVGA;
    config.jpeg_quality = 15;
    config.fb_count = 1;
  }

  if(esp_camera_init(&config) != ESP_OK){
    return;
  }

  // Spustenie streamu
  startCameraServer();
}

void loop() {
  delay(1000);
}

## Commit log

2025-11-05 created logic CAM -> LAPTOP (over http) -> Arduino (over socket), test with brightness data
    [partitions.csv]
2025-12-30 changed functional code, added model for the vehicle
    [chassis.blend, chassis.stl, fork.stl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]
2026-01-10 implemented steering commands
2026-01-15 tweaked model parameters
    [chassis.3mf, chassis.blend, chassis.stl]
2026-01-16 updated wheels
    [wheel.stl]
2026-01-16 changed wheel holder
    [chassis.blend, wheel.stl]
2026-01-26 changed implementation so that the laptop is the server and esp32 is the client
    [partitions.csv]
2026-02-04 changed range for wheels, changed connection and control in python, added rc mode
2026-02-05 Lowered latency in Arduino
2026-02-05 changed skid steering settings to be more extreme
2026-02-07 added steering map
    [steering.ods]
2026-02-10 added debug mode setting and changed steering logic to not cause overflows
2026-02-10 added steering
2026-03-06 changed directory grouping
    [steering.ods]
2026-03-29 finished navrh a implementacia
    [chassis.blend, holder.stl]
2026-04-01 redefined steering logic to tank steer; fixed pwm logic
    [ArduinoController.ino]
2026-04-01 fixed bug that car couldnt go forward
    [ArduinoController.ino]
2026-04-04 added ultrasound sensor diagram
2026-04-25 created: track
2026-04-26 updated: things
    [steering.ods]
2026-04-27 changed: steering
2026-05-06 changed: added folder to readme
    [TestingData.ods]
2026-05-07 added: logo
    [TestingData.ods]
2026-05-18 added: props for cnn testing
    [TestingData.ods]
2026-05-19 changed: debug mode flipping camera
2026-05-19 misc: bug fixes
    [TestingData.ods]
2026-05-20 changed: testing data
    [TestingData.ods]
2026-05-21 final: updated decision logic
    [TestingData.ods]
2026-05-22 added: final testing text, misc attachments
    [TestingData.ods, TestingData.xls]

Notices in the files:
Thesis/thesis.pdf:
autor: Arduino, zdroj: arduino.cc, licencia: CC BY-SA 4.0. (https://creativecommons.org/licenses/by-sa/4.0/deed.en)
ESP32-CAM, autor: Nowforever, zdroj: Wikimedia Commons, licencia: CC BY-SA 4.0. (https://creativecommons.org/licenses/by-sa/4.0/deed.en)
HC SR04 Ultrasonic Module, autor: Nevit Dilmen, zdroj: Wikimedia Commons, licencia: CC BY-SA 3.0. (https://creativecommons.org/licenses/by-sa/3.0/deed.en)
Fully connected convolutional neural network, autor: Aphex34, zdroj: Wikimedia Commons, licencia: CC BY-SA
